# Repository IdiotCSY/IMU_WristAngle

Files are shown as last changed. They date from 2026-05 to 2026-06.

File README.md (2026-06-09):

# IMU_WristAngle: Dual-IMU Wrist Relative Attitude Estimation

本项目面向“前臂 arm - 手部 hand”两刚体结构，使用两个 WT-IMU63 模块分别安装在 arm 端和 hand 端，实现 hand 相对于 arm 的实时相对姿态估计。项目包含 MATLAB 实物实验、Simulink 仿真、STM32F407 实时移植、MATLAB 实时可视化以及后续三自由度参考验证装置建模。

项目核心问题为：

[
{}^A q_H = ({}^W q_A)^{-1} \otimes {}^W q_H
]

其中，({}^W q_A) 表示 arm IMU 相对于世界坐标系的姿态，({}^W q_H) 表示 hand IMU 相对于世界坐标系的姿态，({}^A q_H) 表示 hand 相对于 arm 的相对姿态。

---

## Highlights

* 完成双 IMU 相对姿态的坐标系与四元数推导；
* 实现 WT-IMU63 串口数据解析，包括加速度、角速度、欧拉角和四元数数据帧；
* 在 MATLAB 中实现纯陀螺积分 GI 和自适应 Mahony / MH 姿态融合；
* 在 STM32F407ZGT6 上实现双 IMU 实时姿态解算；
* 使用 USART2 / USART3 分别接收 hand / arm IMU 数据，USART1 与 PC / MATLAB 通信；
* 使用 DMA + IDLE 接收 IMU 数据，并实现逐 gyro 帧姿态更新；
* 在 MATLAB 中实时显示相对 roll / pitch / yaw 和轴角 theta；
* 调研并初步设计三自由度球关节连续测角验证方案。

---

## System Overview

系统基本流程如下：

```text
hand IMU                  arm IMU
   │                         │
   │ USART2                  │ USART3
   └──────────┬──────────────┘
              │
        STM32F407ZGT6
              │
      WT-IMU63 数据解析
              │
      GI / Mahony / MH 姿态解算
              │
 q_rel = q_arm^{-1} ⊗ q_hand
              │
 roll / pitch / yaw / theta
              │
           USART1
              │
         MATLAB 实时显示
```

理论计算如下所示

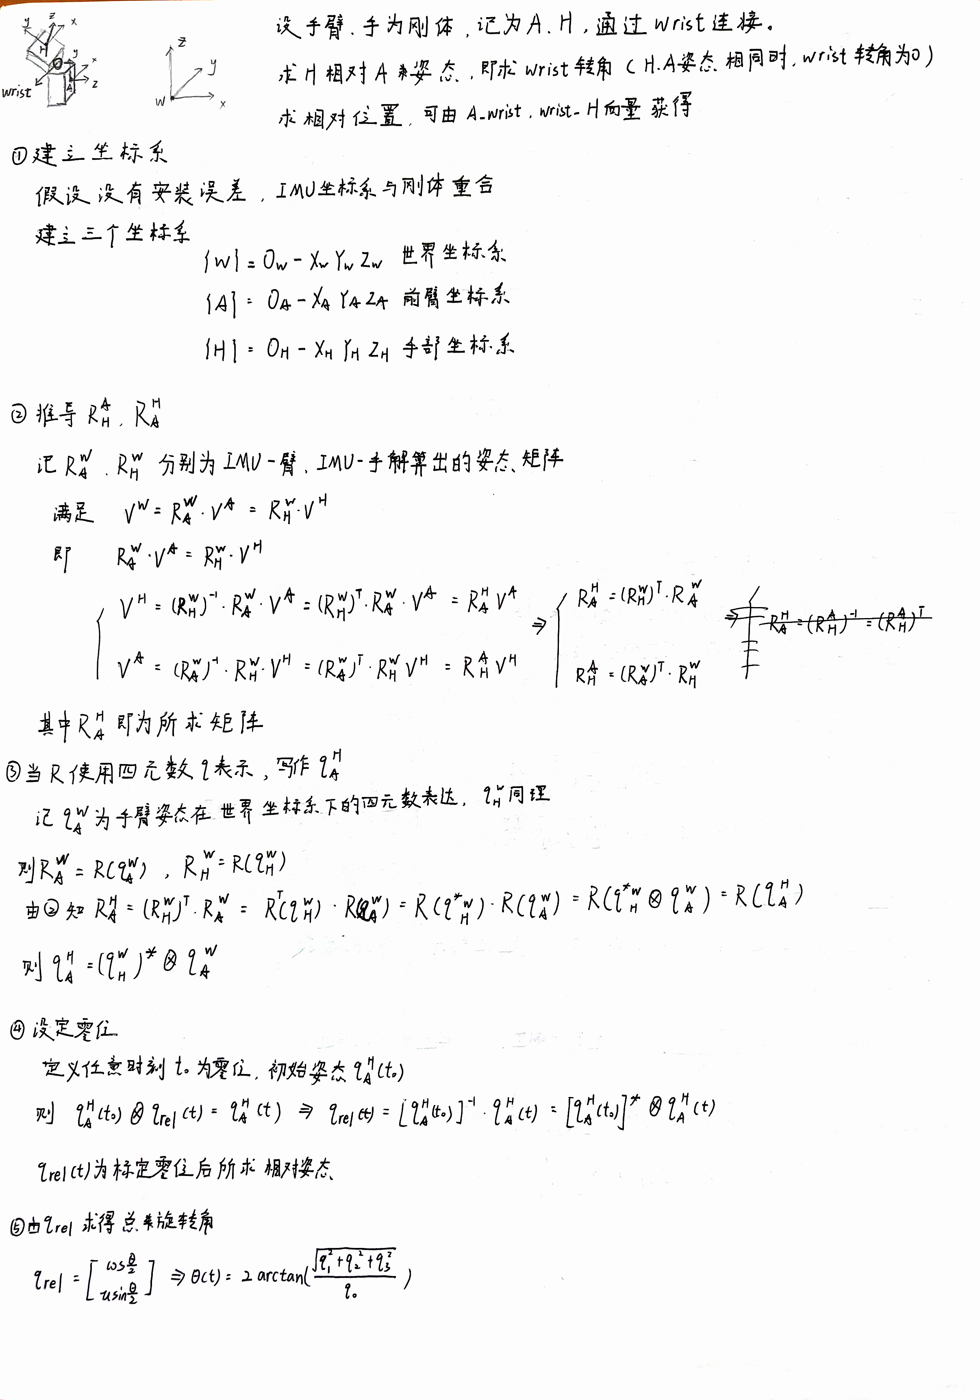
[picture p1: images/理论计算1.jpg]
理论计算1


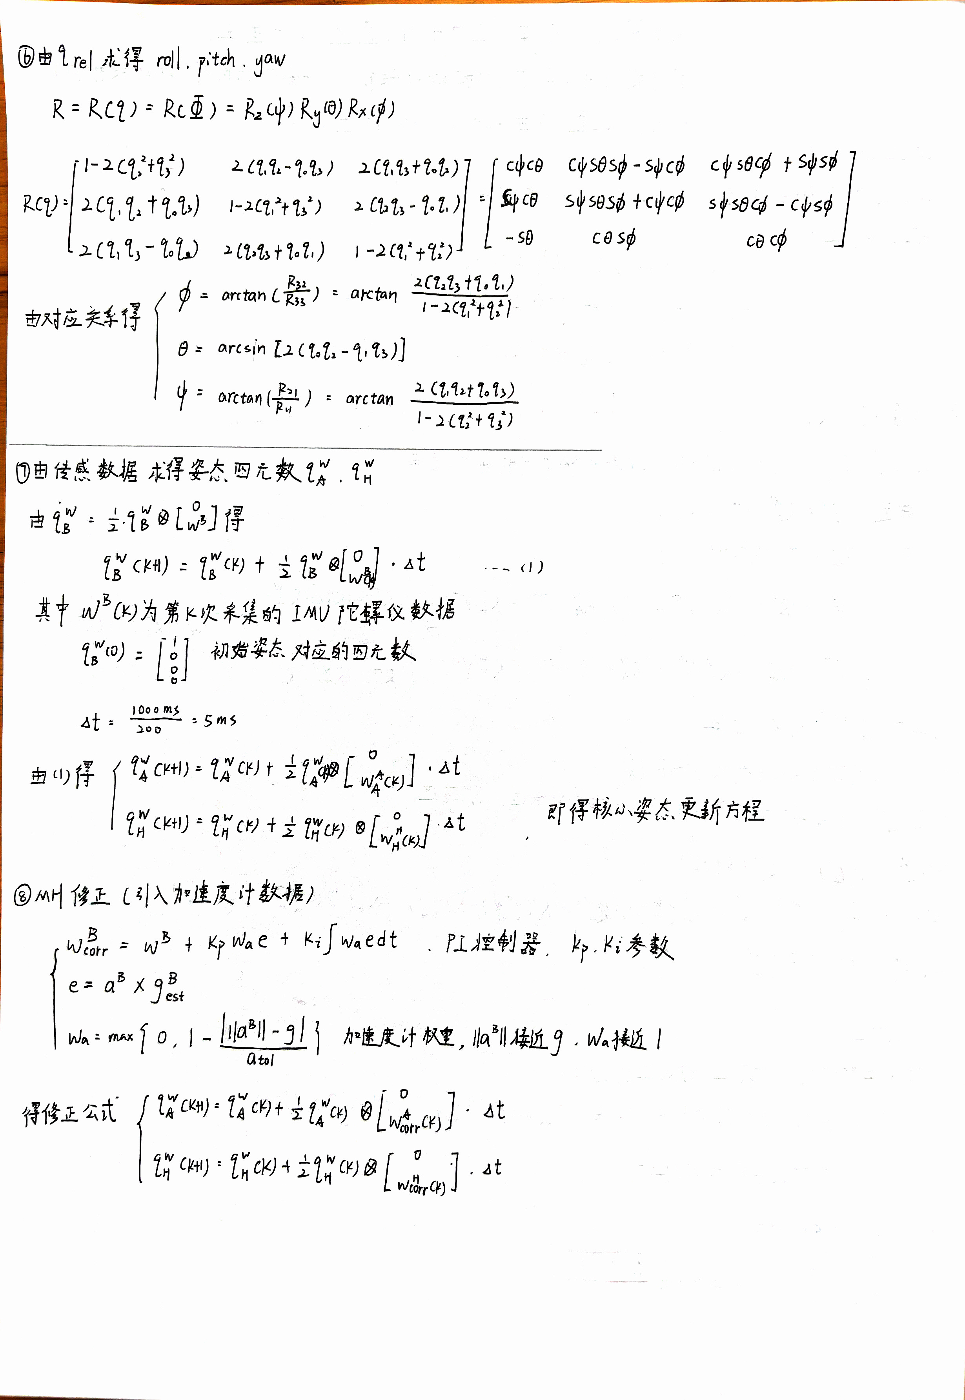
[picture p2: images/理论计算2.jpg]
理论计算2


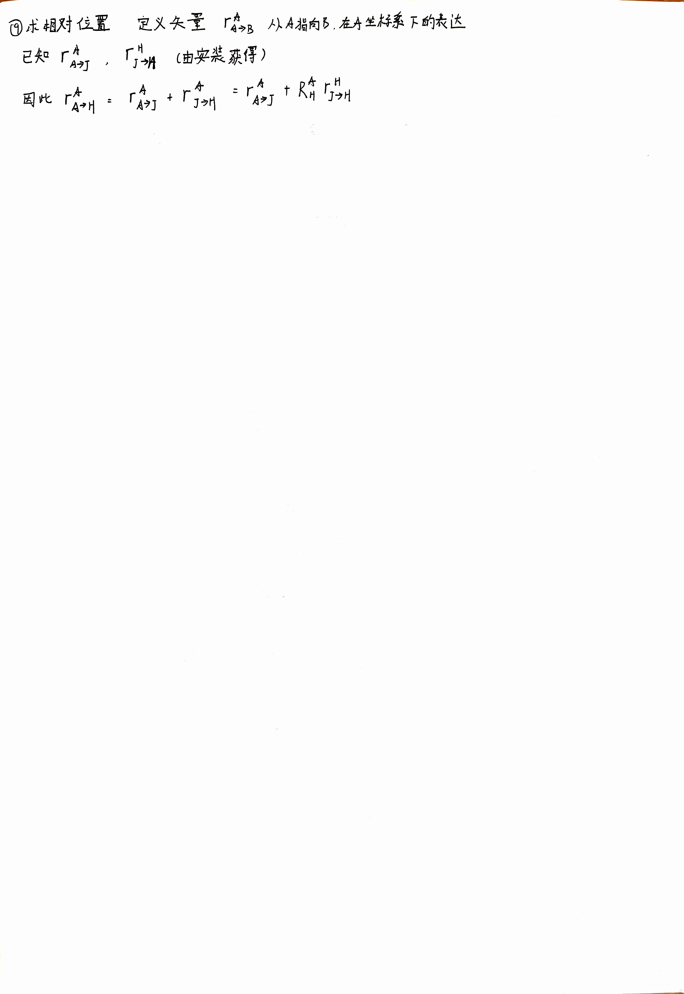
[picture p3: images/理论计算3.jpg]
理论计算3


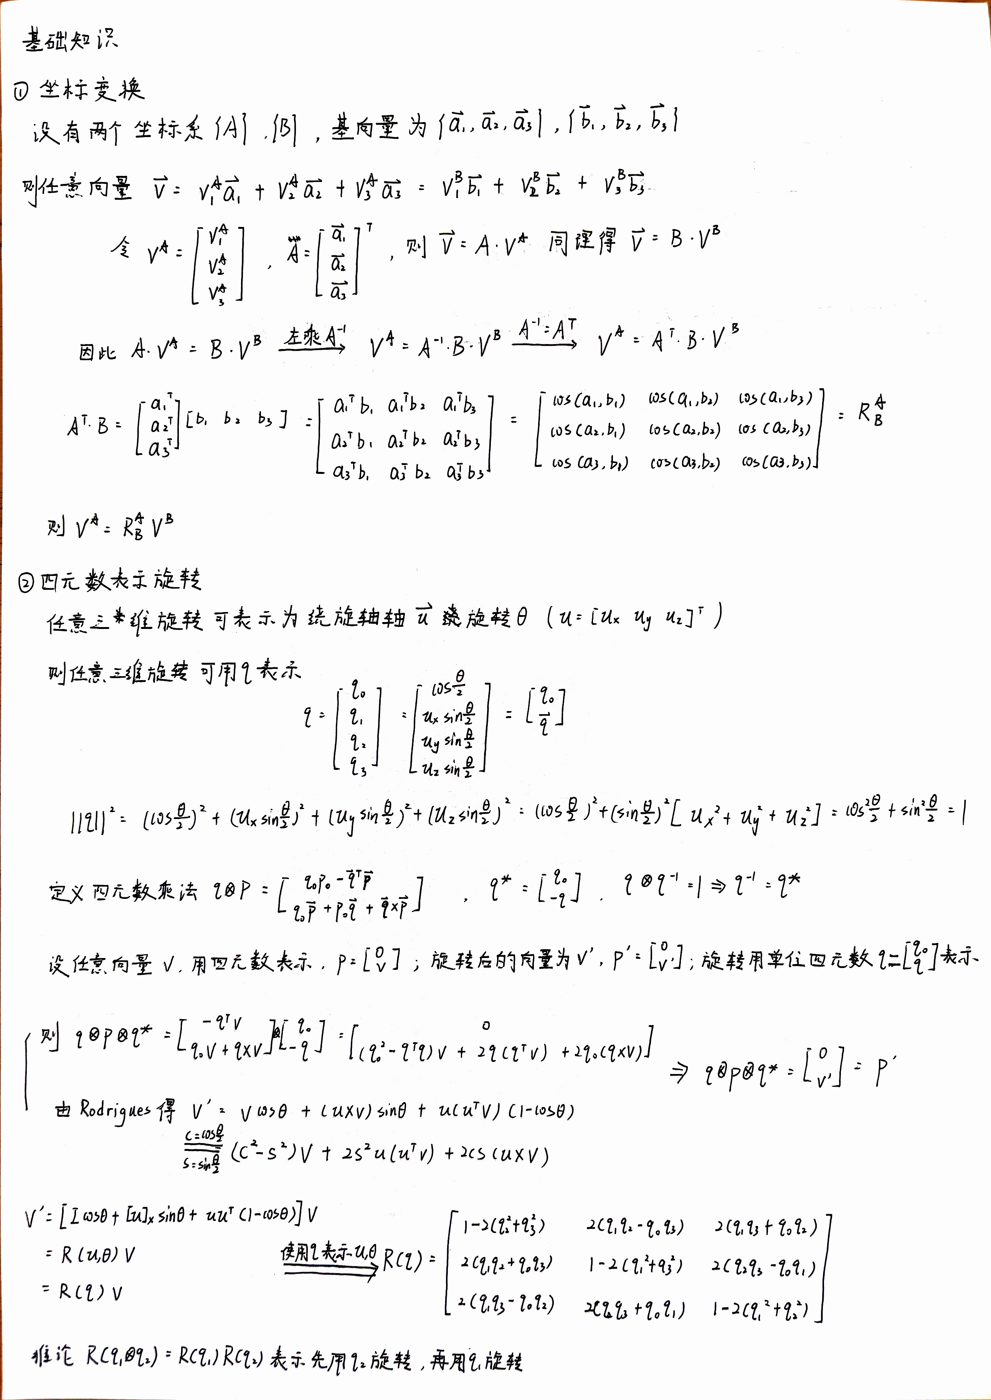
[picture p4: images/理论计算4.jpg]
理论计算4


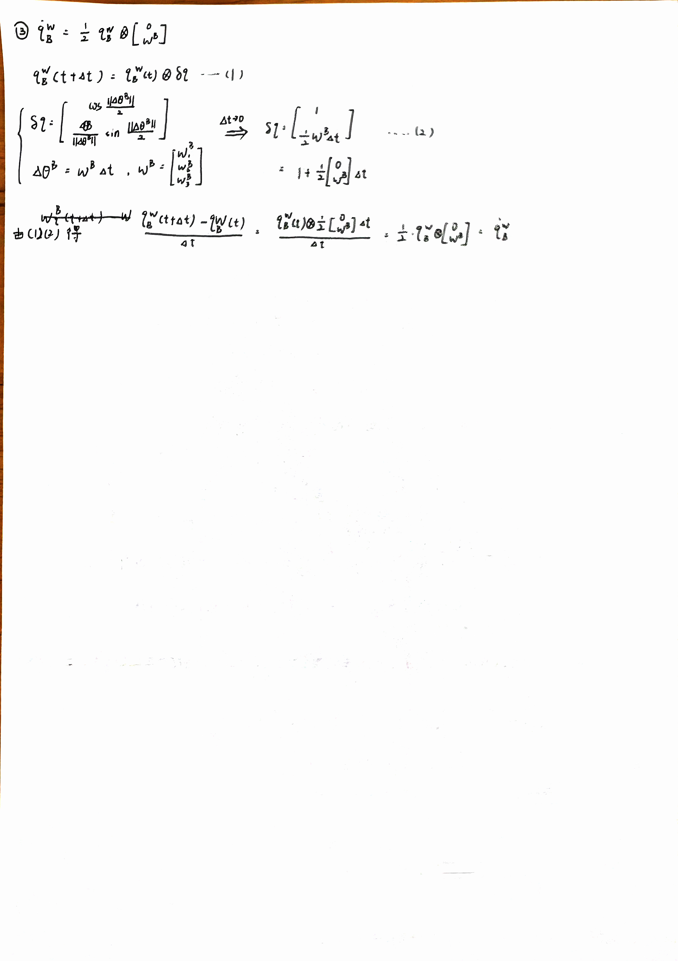
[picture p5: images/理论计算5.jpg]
理论计算5


---

## Repository Structure

```text
IMU_WristAngle/
├── experiment/              # MATLAB 实物实验代码
│   ├── LIBRARY/             # 串口解析、四元数运算、GI、MH、绘图函数
│   ├── test/                # 测试脚本
│   ├── GI_main.m            # 双 IMU 纯陀螺积分主脚本
│   └── MH_main.m            # 双 IMU 自适应 Mahony 主脚本
│
├── simulation/              # Simulink 双 IMU 手腕相对姿态仿真
│   ├── LIBRARY/             # 仿真工具函数
│   ├── SIMULINK/            # Simulink 模型
│   ├── motion_case/         # 预设运动案例
│   ├── init_wrist_imu_sim.m
│   └── post_wrist_imu_sim.m
│
├── mcu/                     # STM32F407 实时解算工程
│   └── STM32F407/           # Keil / CubeMX 工程文件
│
├── model/                   # SolidWorks / STL 打印件与验证装置模型
├── docs/                    # 推导文档、系统图、实验截图
├── references/              # IMU 手册、论文与相关资料
├── .gitignore
└── README.md
```

---

## Hardware Setup

当前实物实验主要使用：

| Module | Description |
| --- | --- |
| IMU | WT-IMU63 |
| MCU | STM32F407ZGT6 |
| PC Software | MATLAB |
| MCU IDE | STM32CubeMX / Keil MDK |
| Communication | UART, 115200 baud |

MATLAB 直连 IMU 实验中：

```text
COM5: hand IMU
COM6: arm IMU
```

STM32 实时实现中：

```text
USART2: hand IMU
USART3: arm IMU
USART1: PC / MATLAB
```

推荐 IMU 设置：

```text
输出内容：角速度 + 加速度
通信速率：115200
回传速率：200 Hz
带宽：188 Hz 或 98 Hz
```

若测试模块内置姿态算法，可设置：

```text
输出内容：四元数 / 欧拉角
通信速率：115200
回传速率：50 Hz 或 200 Hz
```

---

## Mathematical Formulation

建立三个坐标系：

```text
{W}: 世界坐标系
{A}: arm 坐标系
{H}: hand 坐标系
```

假设 IMU 坐标系与对应刚体坐标系重合，则两个 IMU 姿态分别为：

[
{}^W q_A
]

[
{}^W q_H
]

其中，({}^W q_A) 表示 arm 坐标系到世界坐标系的姿态四元数，({}^W q_H) 表示 hand 坐标系到世界坐标系的姿态四元数。

hand 相对于 arm 的相对姿态为：

[
{}^A q_H = ({}^W q_A)^{-1} \otimes {}^W q_H
]

对于单位四元数，有：

[
q^{-1} = q^*
]

因此：

[
{}^A q_H = ({}^W q_A)^* \otimes {}^W q_H
]

实际实验中，初始姿态不一定为零位，因此记录初始相对姿态：

[
{}^A q_{H,0} = {}^A q_H(t_0)
]

任意时刻相对于零位的姿态变化为：

[
q_{out}(t) = ({}^A q_{H,0})^{-1} \otimes {}^A q_H(t)
]

最终输出：

```text
roll / pitch / yaw
axis-angle theta
```

轴角 theta 由下式计算：

[
\theta = 2\operatorname{atan2}(|\mathbf q_v|, q_0)
]

其中：

[
q_{out} =
\begin{bmatrix}
q_0 \
\mathbf q_v
\end{bmatrix}
]

---

## Implemented Algorithms

### 1. WT-IMU63 Protocol Parser

已完成 WT-IMU63 串口数据帧解析，包括：

```text
0x51: acceleration
0x52: angular velocity
0x53: Euler angle
0x59: quaternion
```

相关 MATLAB 函数位于：

```text
experiment/LIBRARY/
```

主要包括：

```matlab
wit_parse_packet.m
wit_parse_stream.m
wit_read_gyro_acc.m
```

---

### 2. Quaternion Utilities

已实现常用四元数工具函数：

```matlab
quat_mul.m
quat_conj.m
quat_normalize.m
quat_to_eulZYX_deg.m
quat_to_axis_angle_deg.m
```

相对姿态计算核心为：

```matlab
qRel = quat_mul(quat_conj(qArm), qHand);
```

即：

[
q_{rel} = q_{arm}^{-1} \otimes q_{hand}
]

---

### 3. Gyro Integration, GI

GI 方法直接使用角速度进行四元数积分：

[
q_{k+1} = q_k \otimes \Delta q(\omega_k)
]

特点：

* 动态响应快；
* 无明显模块内置滤波滞后；
* 长时间运行会存在积分漂移；
* 静止时若角速度输出为 0，则不会继续漂移。

主脚本：

```matlab
experiment/GI_main.m
```

---

### 4. Adaptive Mahony / MH

自适应 Mahony / MH 在 GI 基础上引入加速度计修正：

```text
动态运动时：主要相信 gyro integration
低动态 / 接近静止时：使用 accelerometer 修正 roll / pitch
```

核心逻辑：

```text
如果 |norm(acc) - g| 较小，并且 norm(gyro) 较小：
    提高加速度计修正权重
否则：
    降低或关闭加速度计修正
```

加速度计可信度权重可以表示为：

[
w_a = \max\left(0,\ 1-\frac{||\mathbf a|-g|}{a_{tol}}\right)
]

修正角速度为：

[
\omega_{corr}
=============

## \omega_m

\hat b_g
+
K_p w_a e
+
K_i \int w_a e,dt
]

说明：

* MH 可以改善 roll / pitch 方向的长期漂移；
* 六轴 IMU 缺少绝对航向参考，因此无法从根本上消除 yaw 漂移；
* 当前版本中 `Ki` 默认关闭，以避免引入额外慢漂。

主脚本：

```matlab
experiment/MH_main.m
```

---

## MCU Real-Time Implementation

本项目已将双 IMU 相对姿态解算移植到 STM32F407ZGT6。

MCU 端功能包括：

* USART2 接收 hand IMU 数据；
* USART3 接收 arm IMU 数据；
* USART1 与 PC / MATLAB 通信；
* DMA + IDLE 接收 WT-IMU63 数据帧；
* 每解析到一个有效 gyro 帧，即进行一次 Mahony / MH 更新；
* MCU 端实时计算 hand 相对于 arm 的相对姿态；
* 实时输出 roll / pitch / yaw / theta；
* MATLAB 端仅负责接收、显示和发送置零命令。

当前串口输出格式示例：

```text
ATT,roll,pitch,yaw,theta,handCnt,armCnt,handBad,armBad,handOverflow,armOverflow,handHz,armHz,handDtErrUs,armDtErrUs
```

监测项包括：

```text
hand / arm gyro frame count
bad frame count
queue overflow
actual return frequency
average dt error
DMA receive statistics
```

该部分用于验证 MCU 端能否稳定完成实时双 IMU 姿态解算，而不是依赖 MATLAB 后处理。

---

## Realtime Visualization

MATLAB 实时显示模块位于：

```text
experiment/LIBRARY/imu_realtime_plot_init.m
experiment/LIBRARY/imu_realtime_plot_update.m
experiment/LIBRARY/imu_realtime_plot_reset.m
```

显示内容包括：

* hand IMU 3D attitude；
* arm IMU 3D attitude；
* relative Euler angles: roll / pitch / yaw；
* relative axis-angle rotation angle: theta；
* frame count / bad frame / overflow / dt error 等通信状态。

按键：

```text
z: reset zero pose / clear realtime curves
```

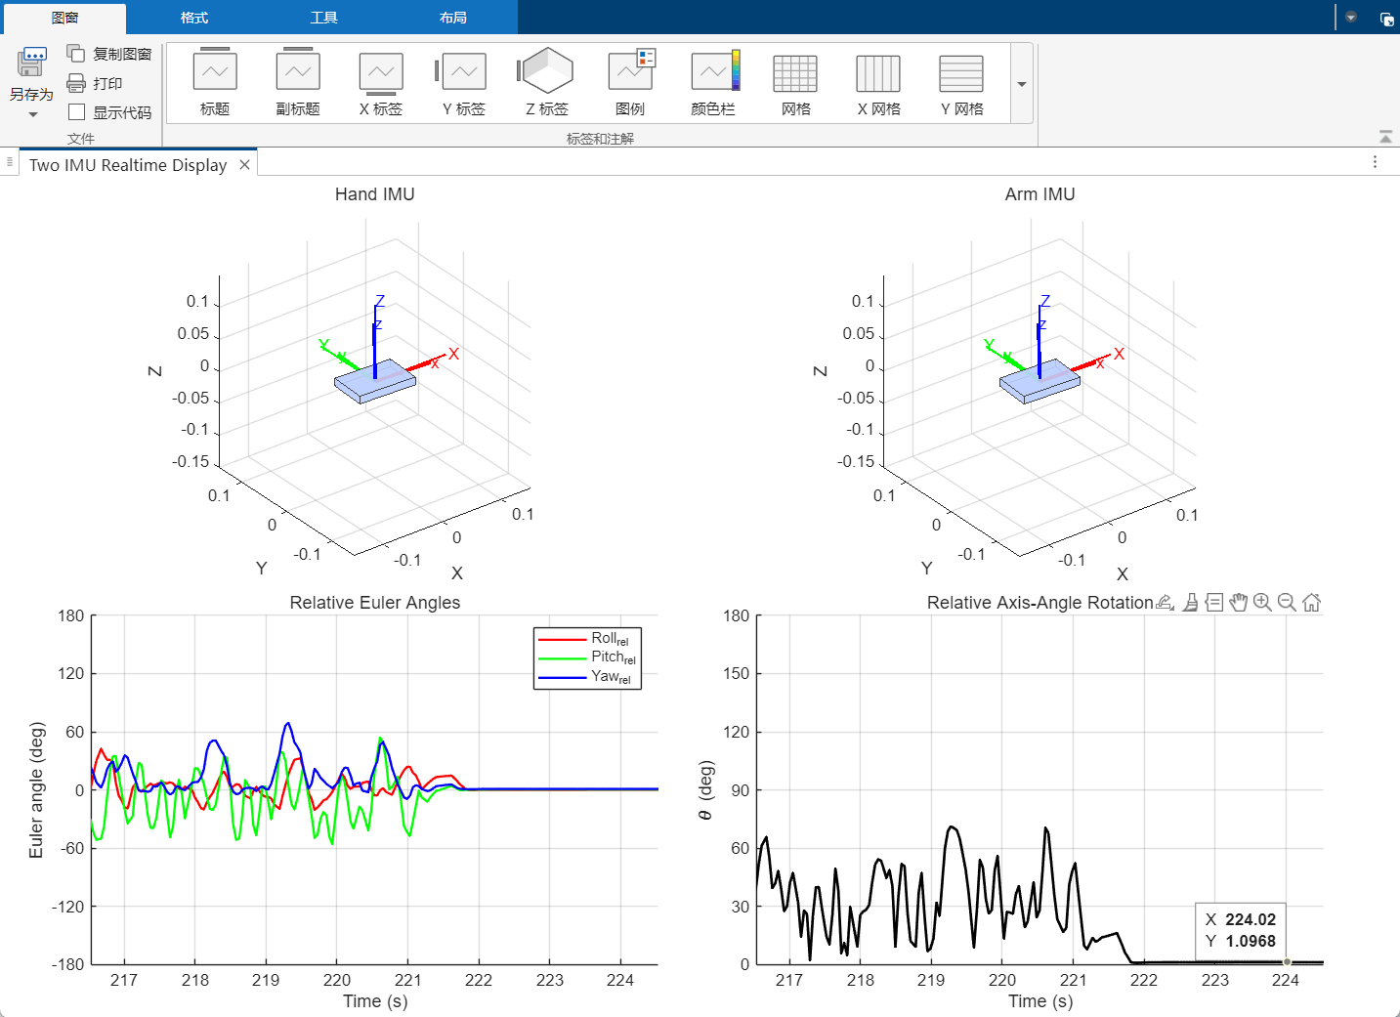
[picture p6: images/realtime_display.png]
realtime_display


---

## Current Results and Observations

| Method | Advantage | Limitation | Observation |
| --- | --- | --- | --- |
| Built-in Quaternion  | 低速运动下较稳定 | 快速运动后存在滞后和 yaw 漂移 | 适合作为模块内置算法参考 |
| Gyro Integration, GI | 动态响应快 | 长时间运行存在积分漂移 | 快速运动跟随能力优于内置四元数 |
| Adaptive Mahony / MH | 可降低 roll / pitch 漂移 | 六轴条件下 yaw 仍缺少绝对参考 | 同刚体动态测试中残余角度低于纯 GI |
| MCU Real-Time MH | 可脱离 MATLAB 实时运行 | 仍需外部参考系统验证动态精度 | 已实现逐 gyro 帧更新和通信状态监测 |

当前阶段的实验现象：

1. 模块内置四元数在低速运动下表现较好，但快速动态运动后容易出现滞后和 yaw 漂移；
2. 纯 GI 方法动态跟随能力更好，但长时间动态运动后会累积误差；
3. 自适应 MH 通过在低动态阶段引入加速度计修正，可以降低 roll / pitch 漂移；
4. 在同刚体动态测试中，自适应 MH 的残余角度低于未修正的 GI；
5. STM32 端已经实现实时相对姿态解算，MATLAB 可实时显示相对欧拉角和轴角。

---

## Simulation

`simulation/` 中包含双 IMU 手腕相对姿态仿真框架，主要模块包括：

* 预定义手腕运动；
* IMU 测量模拟；
* 姿态解算；
* 相对姿态计算；
* 误差分析与后处理。

仿真部分用于在实物实验前验证算法逻辑和误差分析流程。

运行方式：

```matlab
cd simulation
addpath('LIBRARY')
init_wrist_imu_sim
```

运行 Simulink 模型后，执行：

```matlab
post_wrist_imu_sim
```

---

## CAD / Mechanical Model

`model/` 中包含 SolidWorks 零件文件和 STL 文件，用于：

* arm / hand 两侧 IMU 安装；
* 球关节实验装置建模；
* 三自由度连续测角验证装置概念设计。

后续验证装置的目标是为双 IMU 相对姿态估计提供外部参考，包括：

* 三自由度万向节参考平台；
* 三轴编码器 / Hall 角度传感器；
* 球关节连续三自由度测角结构；
* 视觉或非接触姿态参考方案。

模型B

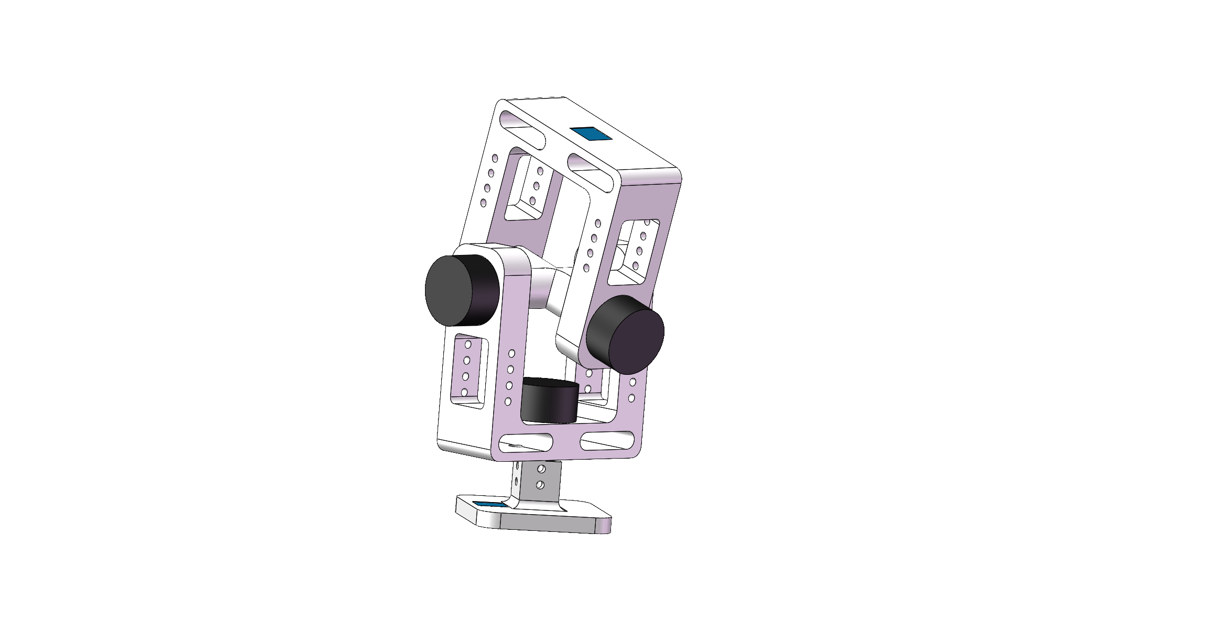
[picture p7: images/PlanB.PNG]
PlanB


模型C

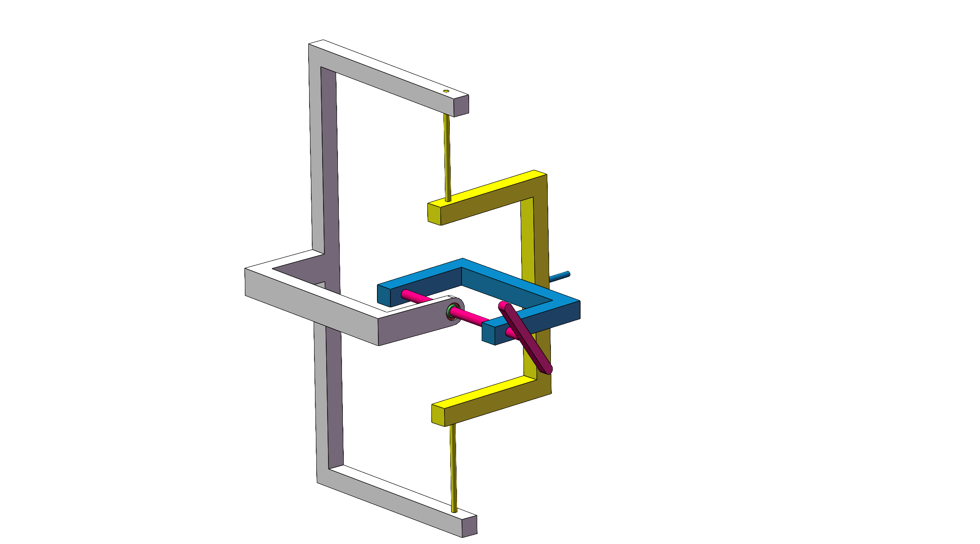
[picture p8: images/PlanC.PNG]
PlanC


---

## How to Run

### MATLAB Experiment

进入 `experiment/` 目录：

```matlab
cd experiment
addpath('LIBRARY')
```

运行 GI：

```matlab
GI_main
```

运行自适应 Mahony / MH：

```matlab
MH_main
```

### MATLAB Simulation

进入 `simulation/` 目录：

```matlab
cd simulation
addpath('LIBRARY')
init_wrist_imu_sim
```

运行 Simulink 模型后处理：

```matlab
post_wrist_imu_sim
```

### MCU

进入 MCU 工程目录：

```text
mcu/STM32F407/
```

使用 Keil MDK 打开工程后：

1. 编译工程；
2. 下载到 STM32F407ZGT6；
3. 连接 hand IMU 到 USART2；
4. 连接 arm IMU 到 USART3；
5. 连接 PC / MATLAB 到 USART1；
6. 运行 MATLAB 实时显示脚本。

---

## Next Steps

后续计划：

* 增加 MATLAB 自动数据保存与离线误差分析；
* 统计 zero-return error、dynamic tracking error 和 long-term drift；
* 设计三自由度连续参考测角实验；
* 对比双 IMU 输出和外部参考角；
* 进一步研究球关节约束、回零约束和运动学约束在相对姿态估计中的作用。

---

## Notes

当前项目仍处于实验验证阶段，实时显示结果主要用于观察算法趋势。严格性能评价应基于保存数据后的离线分析，包括：

* final theta；
* max theta；
* RMS theta；
* relative Euler angle drift；
* zero-return error；
* dynamic response delay；
* long-term drift；
* dynamic tracking error。

---

## Author

Chen Shuyi
Wuhan University of Technology
Mechanical Design, Manufacturing and Automation

GitHub: [IdiotCSY](https://github.com/IdiotCSY)

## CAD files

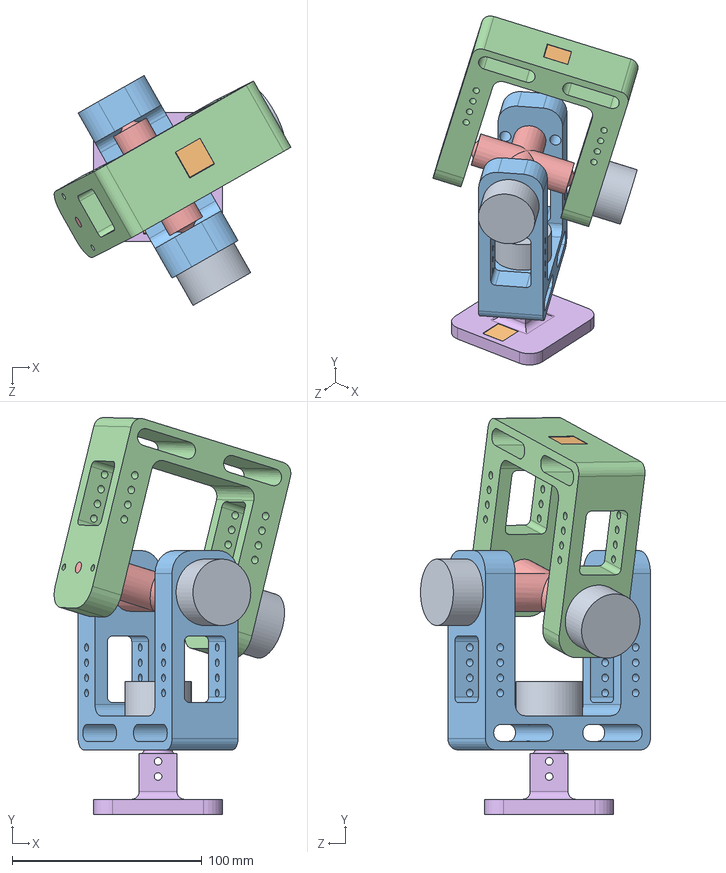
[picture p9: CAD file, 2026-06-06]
model/PlanB/三自由度云台.SLDASM
124.7 x 209.1 x 121.1 mm
底座
十字架
支架A
支架B
IMU x 2
编码器 x 3

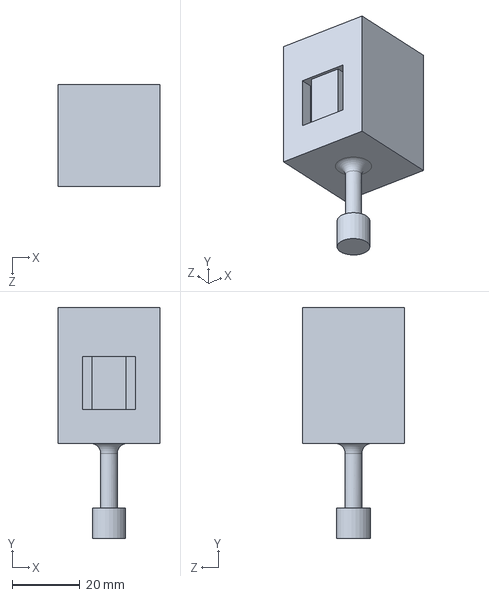
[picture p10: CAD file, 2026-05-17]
model/PlanA/hand5.16.SLDPRT
30.0 x 68.0 x 30.0 mm

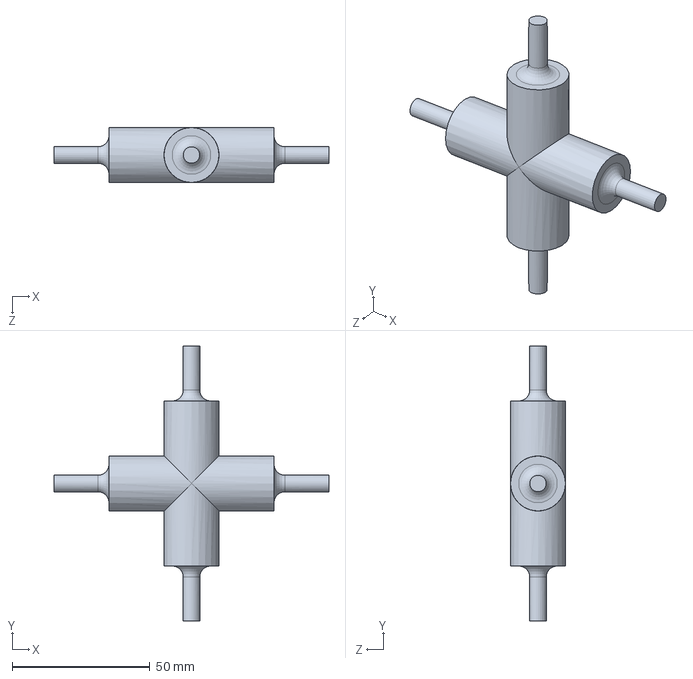
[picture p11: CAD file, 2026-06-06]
model/PlanB/十字架.SLDPRT
100.0 x 100.0 x 20.0 mm

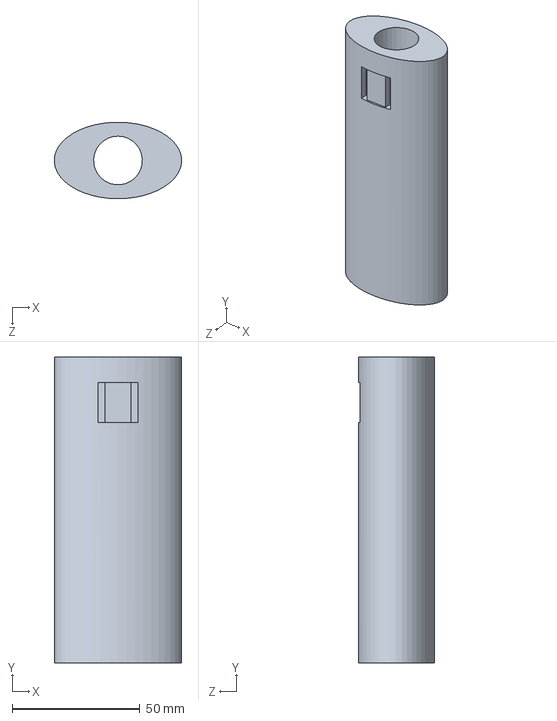
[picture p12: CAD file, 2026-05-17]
model/PlanA/arm5.14.SLDPRT
50.0 x 120.0 x 30.0 mm

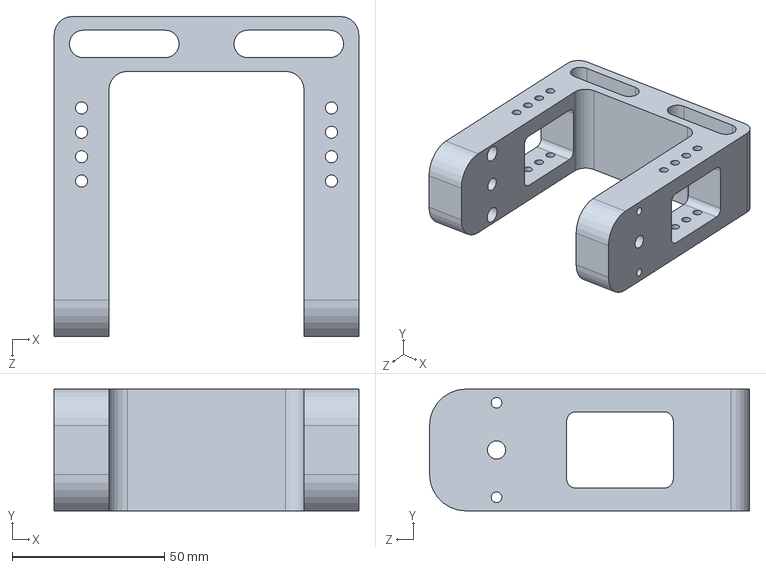
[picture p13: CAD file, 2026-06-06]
model/PlanB/支架A.SLDPRT
100.0 x 40.0 x 105.0 mm

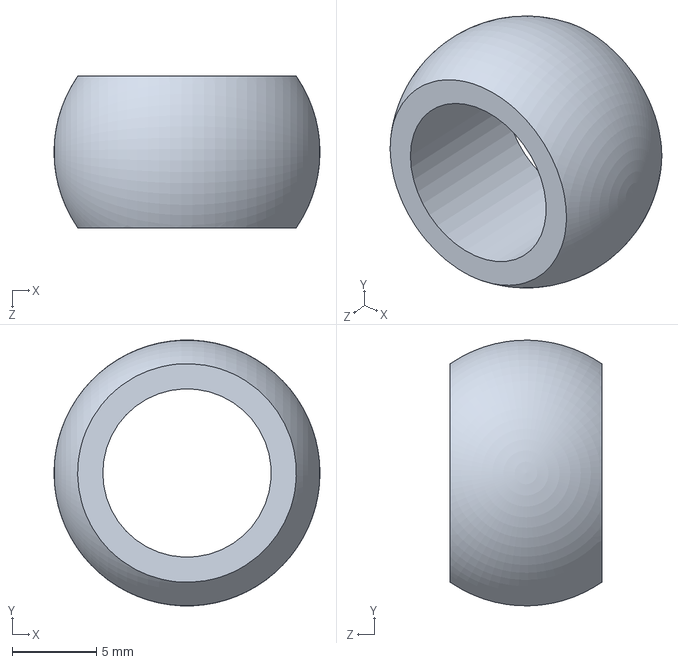
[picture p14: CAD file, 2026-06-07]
model/PlanC/内轴承.SLDPRT
15.8 x 15.8 x 9.00 mm

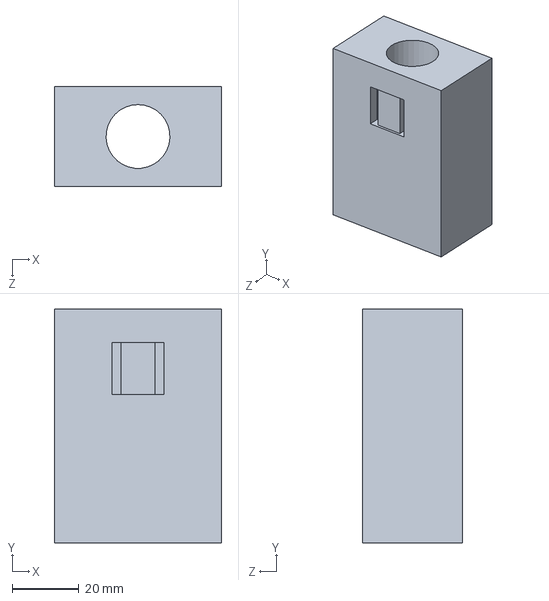
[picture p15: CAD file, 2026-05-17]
model/PlanA/arm5.16.SLDPRT
50.0 x 70.0 x 30.0 mm

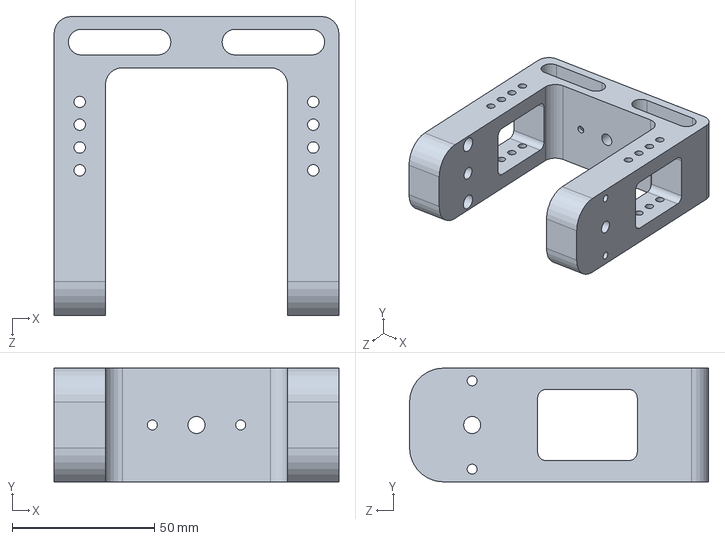
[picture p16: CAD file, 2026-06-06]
model/PlanB/支架B.SLDPRT
100.0 x 40.0 x 105.0 mm

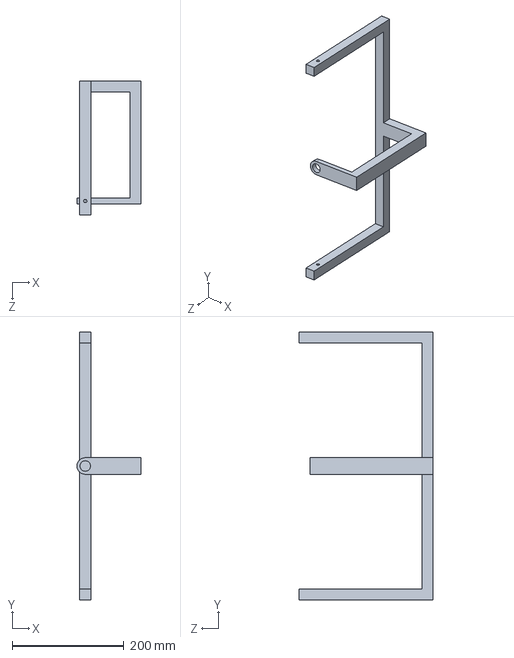
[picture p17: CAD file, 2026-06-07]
model/PlanC/外环.SLDPRT
115.0 x 480.0 x 240.0 mm

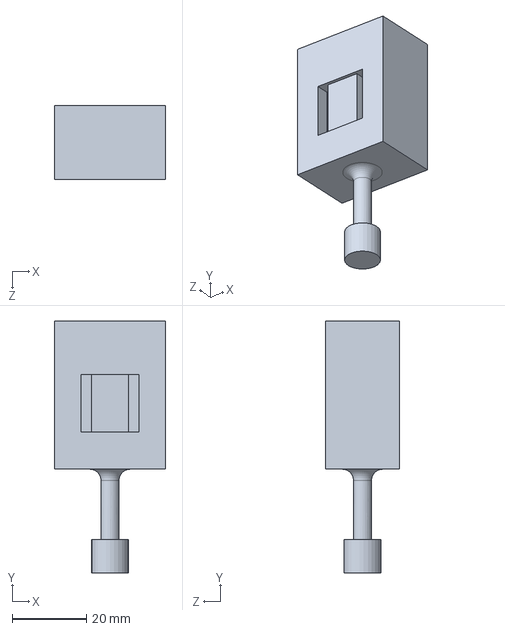
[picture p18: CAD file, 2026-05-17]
model/PlanA/hand5.14.SLDPRT
30.0 x 68.0 x 20.0 mm

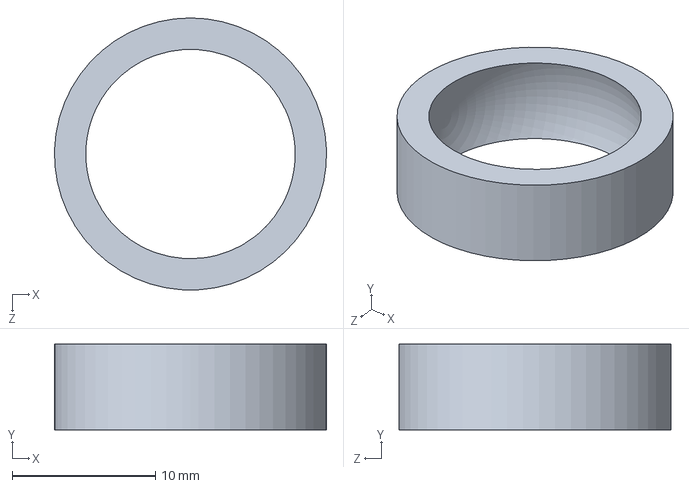
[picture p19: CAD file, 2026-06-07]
model/PlanC/外轴承.SLDPRT
19.0 x 6.00 x 19.0 mm

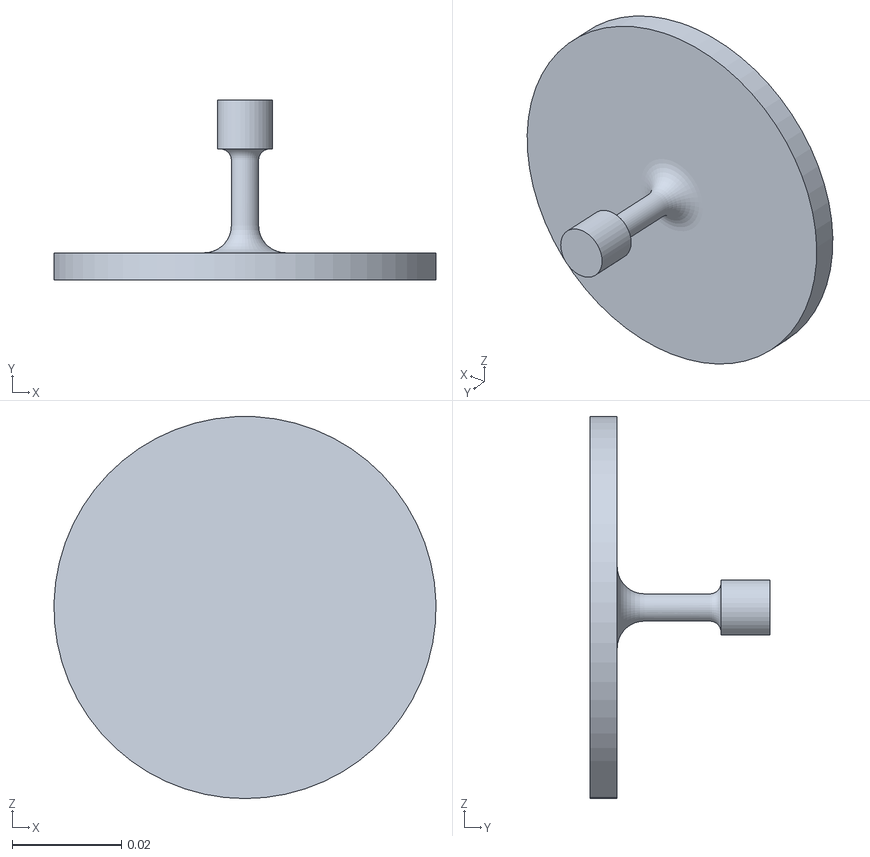
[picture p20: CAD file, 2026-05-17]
model/PlanA/底座5.16.STL
0.07 x 0.033 x 0.07

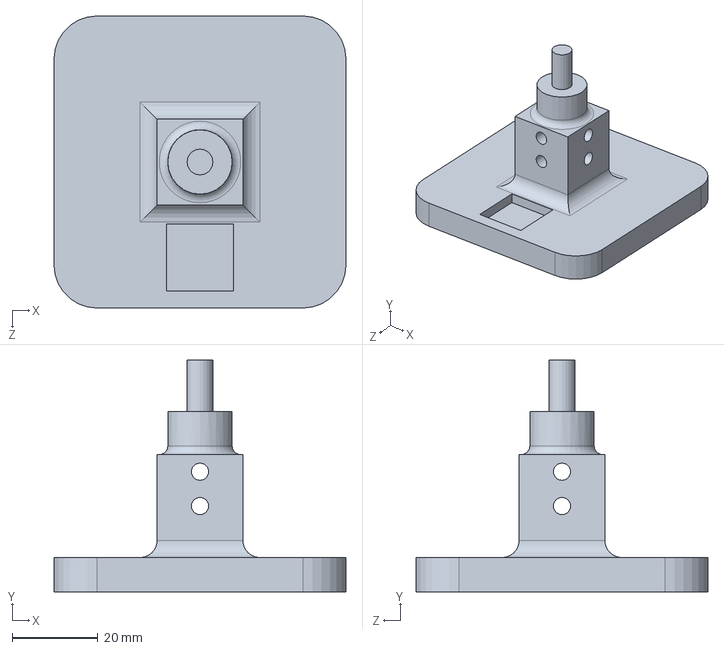
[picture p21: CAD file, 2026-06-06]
model/PlanB/底座.SLDPRT
68.0 x 54.0 x 68.0 mm

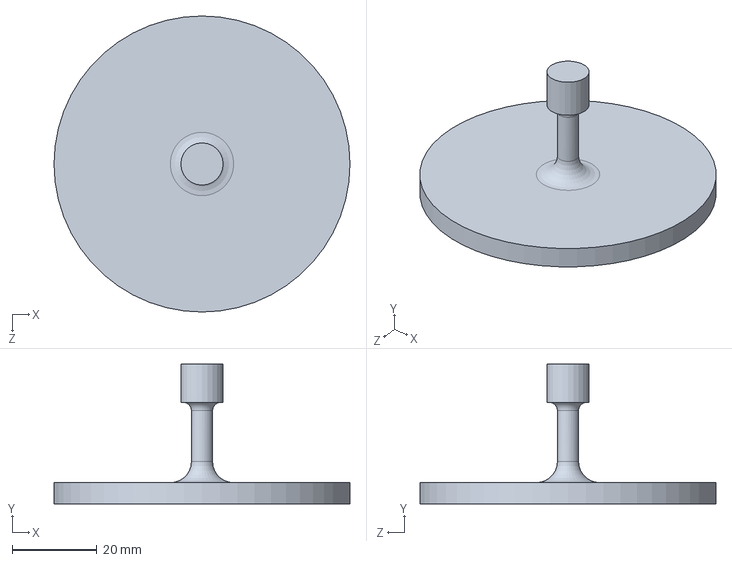
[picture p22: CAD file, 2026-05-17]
model/PlanA/底座.SLDPRT
70.0 x 33.0 x 70.0 mm

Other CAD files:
model/PlanC/装置.SLDASM
model/PlanB/IMU.SLDPRT
model/PlanB/编码器.SLDPRT
model/PlanA/arm5.14.STL
model/PlanA/arm5.16.STL
model/PlanA/hand5.14.STL
model/PlanA/hand5.16.STL
model/PlanA/底座.STL

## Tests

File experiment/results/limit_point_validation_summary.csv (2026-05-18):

位置编号 | 验证次数 | 平均轴角误差_deg | 最大轴角误差_deg | 轴角误差标准差_deg | 平均Roll绝对误差_deg | 平均Pitch绝对误差_deg | 平均Yaw绝对误差_deg
1 | 7 | 0.82294193497472 | 1.76674946729153 | 0.525273822321154 | 0.186895211024847 | 0.157248412501579 | 0.753047696472164
2 | 7 | 1.04471775784266 | 2.06726702708496 | 0.794306813042779 | 0.311217182955533 | 0.148710812020316 | 0.924472406353605
3 | 7 | 1.01177905972943 | 1.87416659136141 | 0.666744488745707 | 0.959299051007097 | 0.237845580329731 | 0.102019066601327
4 | 7 | 1.02979910614819 | 2.12288395523191 | 0.756805435630179 | 0.876189501243273 | 0.23502891488053 | 0.355434098059025
5 | 7 | 1.57949992714125 | 1.83694443291025 | 0.217233414040236 | 0.935826150621499 | 1.02322198942863 | 0.620983233941567
6 | 5 | 0.927531624248803 | 1.81863336110521 | 0.574196154516952 | 0.772531100489709 | 0.188170583880674 | 0.407425637201953

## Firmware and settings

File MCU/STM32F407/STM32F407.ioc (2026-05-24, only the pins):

Mcu.UserName=STM32F407ZGTx
PA10.Signal=USART1_RX
PA13.Signal=SYS_JTMS-SWDIO
PA14.Signal=SYS_JTCK-SWCLK
PA2.Signal=USART2_TX
PA3.Signal=USART2_RX
PA9.Signal=USART1_TX
PB10.Signal=USART3_TX
PB11.Signal=USART3_RX
PH0-OSC_IN.Signal=RCC_OSC_IN
PH1-OSC_OUT.Signal=RCC_OSC_OUT

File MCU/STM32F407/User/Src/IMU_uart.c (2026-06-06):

#include "imu_uart.h"
#include "usart.h"

#include <stdio.h>
#include <string.h>

/*
 * ===================== 文件逻辑说明 =====================
 *
 * 本文件负责把“串口通信”和“双 IMU 姿态算法”连接起来。
 *
 * 当前版本重点：
 *
 *   每解析到一个有效 GYRO 帧，就生成一个 IMU_Sample_t；
 *   主循环逐个取出 sample；
 *   每个 sample 都调用一次 DualIMU_UpdateOne()。
 *
 * 这样可以避免旧版中：
 *
 *   DMA 一次收到多帧，但主循环只用最新一帧更新一次
 *
 * 所导致的中间帧漏积分问题。
 */

/* ===================== 参数设置 ===================== */

/*
 * IMU DMA 接收缓冲区大小。
 *
 * WIT 一帧 11 字节。
 * ACC + GYRO 一组约 22 字节。
 */
#define IMU_RX_BUF_SIZE          256

/*
 * PC 命令接收缓冲区。
 * MATLAB 当前只发 z，64 字节足够。
 */
#define PC_RX_BUF_SIZE           64

/*
 * PC 输出字符串缓冲区。
 */
#define PC_TX_BUF_SIZE           256

/*
 * IMU 采样频率。
 *
 * 当前仍然使用固定 dt。
 * 如果维特上位机设置为 200 Hz，这里保持 200。
 * 如果设置为 100 Hz，这里改成 100。
 *
 * 下一步我们再用 TIM2 改成实测 dt。
 */
#define IMU_SAMPLE_FREQ_HZ       200.0f
#define IMU_SAMPLE_DT            (1.0f / IMU_SAMPLE_FREQ_HZ)

/*
 * STM32 向 MATLAB 输出频率。
 *
 * 20 ms 输出一次，大约 50 Hz。
 */
#define PC_OUTPUT_PERIOD_MS      20

/*
 * 每个 IMU 的 sample 队列长度。
 *
 * 200 Hz 下，64 个 sample 相当于 0.32 s 缓冲。
 * 正常主循环远快于这个速度，不应该溢出。
 */
#define IMU_SAMPLE_QUEUE_SIZE    64

#define DT_MONITOR_PERIOD_MS     1000U
#define TARGET_DT_US             (1000000.0f / IMU_SAMPLE_FREQ_HZ)

/* ===================== 数据结构定义 ===================== */

/*
 * 一个 IMU 姿态更新样本。
 *
 * 每解析到一个 GYRO 帧，就生成一个 sample。
 *
 * gyro_deg_s:
 *   当前 GYRO 帧对应的角速度，单位 deg/s。
 *
 * acc_mps2:
 *   最近一次解析到的加速度，单位 m/s^2。
 *
 * 说明：
 *   WIT 数据是分帧发的，ACC 和 GYRO 不在同一帧里。
 *   所以当 GYRO 帧到来时，使用“最近一次 ACC”配合它更新 Mahony。
 */
typedef struct
{
    Vec3f_t gyro_deg_s;
    Vec3f_t acc_mps2;

} IMU_Sample_t;

/*
 * 简单环形队列。
 *
 * push:
 *   在串口 DMA 回调中执行。
 *
 * pop:
 *   在主循环中执行。
 *
 * overflow_count:
 *   如果主循环处理不过来，队列满了，新样本会被丢弃，
 *   overflow_count 会增加。
 */
typedef struct
{
    IMU_Sample_t buf[IMU_SAMPLE_QUEUE_SIZE];

    uint16_t head;
    uint16_t tail;
    uint16_t count;

    uint32_t pushed_count;
    uint32_t popped_count;
    uint32_t overflow_count;

} IMU_SampleQueue_t;

/* ===================== 静态变量 ===================== */

/* USART2 / USART3 的 DMA 接收缓冲区 */
static uint8_t imu_hand_rx_buf[IMU_RX_BUF_SIZE];
static uint8_t imu_arm_rx_buf[IMU_RX_BUF_SIZE];

/* USART1 接收 MATLAB 命令的缓冲区 */
static uint8_t pc_rx_buf[PC_RX_BUF_SIZE];

/* WIT 协议解析器 */
static WIT_Parser_t wit_hand;
static WIT_Parser_t wit_arm;

/* 双 IMU 姿态系统 */
static DualIMU_t dual_imu;

/* hand / arm 各自的 sample 队列 */
static IMU_SampleQueue_t hand_queue;
static IMU_SampleQueue_t arm_queue;

/* PC 输出计时 */
static uint32_t last_output_tick = 0;

/* dt / 频率监测变量 */
static uint32_t last_dt_monitor_tick = 0;

static uint32_t last_hand_cnt_for_hz = 0;
static uint32_t last_arm_cnt_for_hz  = 0;

static float hand_hz = 0.0f;
static float arm_hz  = 0.0f;

static float hand_dt_avg_us = 0.0f;
static float arm_dt_avg_us  = 0.0f;

static float hand_dt_err_us = 0.0f;
static float arm_dt_err_us  = 0.0f;

/* ===================== DMA 单次接收监测变量 ===================== */

/*
 * 用来观察：
 *   1. 一次 DMA 回调收到了多少字节；
 *   2. 一次 DMA 回调中解析出了多少个 GYRO 帧；
 *   3. 平均每次 DMA 回调包含多少个 GYRO 帧；
 *   4. 最大一次 DMA 回调包含多少个 GYRO 帧。
 *
 * 目的：
 *   直观验证“逐 GYRO 帧更新 Mahony”相比旧逻辑的必要性。
 */

static uint32_t hand_dma_event_count = 0;
static uint32_t arm_dma_event_count  = 0;

static uint32_t hand_dma_total_gyro_frames = 0;
static uint32_t arm_dma_total_gyro_frames  = 0;

static uint16_t hand_dma_last_bytes = 0;
static uint16_t arm_dma_last_bytes  = 0;

static uint16_t hand_dma_last_gyro_frames = 0;
static uint16_t arm_dma_last_gyro_frames  = 0;

static uint16_t hand_dma_max_gyro_frames = 0;
static uint16_t arm_dma_max_gyro_frames  = 0;

static float hand_dma_avg_gyro_frames = 0.0f;
static float arm_dma_avg_gyro_frames  = 0.0f;

/* ===================== 内部函数声明 ===================== */

static void IMU_UART_StartReceive(void);
static void IMU_UART_RestartReceive(UART_HandleTypeDef *huart);

static void IMU_UART_UpdateAlgorithm(void);
static void IMU_UART_OutputToPC(void);

static void IMU_UART_ProcessPCCommand(const uint8_t *data, uint16_t len);
static void IMU_UART_Print(const char *str);

/* 队列相关函数 */
static void IMU_SampleQueue_Init(IMU_SampleQueue_t *q);
static void IMU_SampleQueue_Push(IMU_SampleQueue_t *q, IMU_Sample_t sample);
static uint8_t IMU_SampleQueue_Pop(IMU_SampleQueue_t *q, IMU_Sample_t *sample);

/* WIT 帧回调函数 */
static void IMU_UART_WitFrameCallbackHand(WIT_Parser_t *parser,
                                          uint8_t frame_type,
                                          void *user_data);

static void IMU_UART_WitFrameCallbackArm(WIT_Parser_t *parser,
                                         uint8_t frame_type,
                                         void *user_data);

static void IMU_UART_UpdateDtMonitor(void);

/* ===================== 对外函数实现 ===================== */

void IMU_UART_Init(void)
{
    //初始化计时变量
    last_dt_monitor_tick = HAL_GetTick();
    last_hand_cnt_for_hz = 0;
    last_arm_cnt_for_hz  = 0;

    hand_hz = 0.0f;
    arm_hz  = 0.0f;

    hand_dt_avg_us = 0.0f;
    arm_dt_avg_us  = 0.0f;

    hand_dt_err_us = 0.0f;
    arm_dt_err_us  = 0.0f;

    /*
     * 初始化两个 WIT 协议解析器。
     */
    WIT_Init(&wit_hand);
    WIT_Init(&wit_arm);

    /*
     * 初始化双 IMU 姿态系统。
     */
    DualIMU_Init(&dual_imu);

    /*
     * 初始化 hand / arm 两个 sample 队列。
     */
    IMU_SampleQueue_Init(&hand_queue);
    IMU_SampleQueue_Init(&arm_queue);

    last_output_tick = HAL_GetTick();

    /*
     * 启动 USART1 / USART2 / USART3 的 DMA + IDLE 接收。
     */
    IMU_UART_StartReceive();

    /*
     * 启动提示。
     * MATLAB 会忽略非 ATT 开头的行。
     */
    IMU_UART_Print("\r\n==============================\r\n");
    IMU_UART_Print("STM32 Dual IMU Attitude Start\r\n");
    IMU_UART_Print("Mode: per-gyro-frame Mahony update\r\n");
    IMU_UART_Print("USART1 -> PC / MATLAB\r\n");
    IMU_UART_Print("USART2 -> hand IMU\r\n");
    IMU_UART_Print("USART3 -> arm  IMU\r\n");
    IMU_UART_Print("Output: ATT,roll,pitch,yaw,theta,handCnt,armCnt,handBad,armBad\r\n");
    IMU_UART_Print("Command: send 'z' to set zero\r\n");
    IMU_UART_Print("==============================\r\n\r\n");
}

void IMU_UART_Task(void)
{
    /*
     * 主循环任务：
     *
     *   1. 从 hand / arm 队列逐个取 sample；
     *   2. 每个 sample 调用一次 Mahony；
     *   3. 更新相对姿态；
     *   4. 周期性输出到 MATLAB。
     */
    IMU_UART_UpdateAlgorithm();

    /* 更新实际采样频率 / 平均 dt 误差 */
    IMU_UART_UpdateDtMonitor();

    IMU_UART_OutputToPC();
}

void IMU_UART_SetZero(void)
{
    /*
     * 注意：
     *   这里不重置 hand_filter.q / arm_filter.q。
     *   只把当前 qRel 记录为零位 qRel0。
     */
    DualIMU_SetZero(&dual_imu);

    IMU_UART_Print("ZERO SET\r\n");
}

WIT_Parser_t* IMU_UART_GetHandParser(void)
{
    return &wit_hand;
}

WIT_Parser_t* IMU_UART_GetArmParser(void)
{
    return &wit_arm;
}

DualIMU_t* IMU_UART_GetDualIMU(void)
{
    return &dual_imu;
}

/* ===================== HAL 回调函数 ===================== */
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

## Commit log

2026-05-17 Initial commit: dual IMU wrist angle estimation
    [arm5.14.SLDPRT, arm5.14.STL, arm5.16.SLDPRT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]
2026-05-17 Update README for current project structure
2026-05-17 把各个算法（GI、MH）放在了main文件夹中
2026-05-17 增加了双 IMU 自适应 MH + 6 个物理限位点验证实验MH_validate_points.m以及修改了MH_main
2026-05-17 增加了由数据记录转换为图表的脚本
    [limit_point_validation_summary.csv]
2026-05-18 add new test data
    [limit_point_validation_summary.csv]
2026-06-06 增加了三自由度云台模型以及有关MCU显示图像的新脚本以及新的论文参考
    [IMU.SLDPRT, arm5.14.SLDPRT, arm5.14.STL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]
2026-06-07 增加了PlanC的建模
    [内轴承.SLDPRT, 外环.SLDPRT, 外轴承.SLDPRT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]
2026-06-09 新增理论计算
2026-06-09 更新readme图片
2026-06-09 新增readme图片
    [装置.SLDASM]
2026-06-09 修改readme图片格式
2026-06-09 修改readme图片引用
